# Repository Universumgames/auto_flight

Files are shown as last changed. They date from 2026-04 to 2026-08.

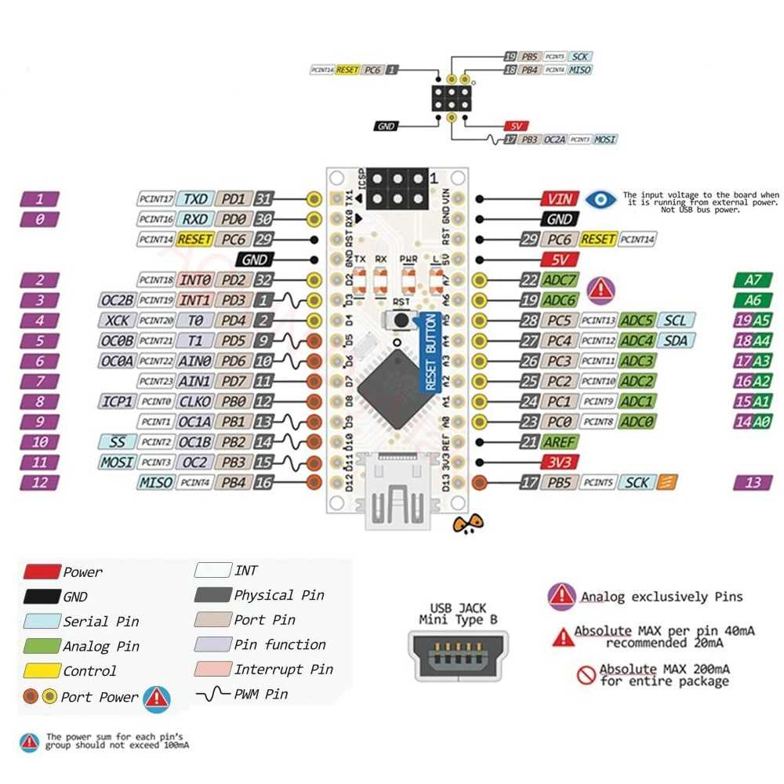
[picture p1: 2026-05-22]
resources/arduino-nano-pinout-pwm-lgr.jpg

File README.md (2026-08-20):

# Auto Flight

Autonomous glider for area-coverage flights — technical documentation.

"Auto Flight" is an autonomous glider that independently flies over predefined areas (e.g. agricultural fields) in a lawn-mower (meander) pattern. Navigation is achieved through a combination of GPS, accelerometer/gyroscope (IMU), magnetometer, and barometer. Throughout the flight, the plane stays in contact with a ground station via a long-range radio link (LoRa), which provides a web interface for mission planning and live monitoring. In an emergency, the plane can be taken over manually at any time via an off-the-shelf RC transmitter.

The system consists of three independent firmware/software projects (the flight controller in the plane, the ground station, and a servo/motor controller) as well as a number of shared components and tools:

| Project | Platform | Task |
|---|---|---|
| [`flight_controller/`](./flight_controller) | ESP-IDF (ESP32-S3) | Main computer in the plane: route planning, sensors, flight control, LoRa communication |
| [`base_station/`](./base_station) | ESP-IDF (ESP32-S3) | Ground station: WiFi access point, web UI server, LoRa relay |
| [`motor_controller/`](./motor_controller) | PlatformIO/Arduino (ATmega328) | Control-surface/motor actuation, SBUS reception, safety override |
| [`frontend_web/`](./frontend_web) | Vue 3 + TypeScript | Ground station user interface (mission planning, live telemetry) |
| [`shared_components/`](./shared_components) | ESP-IDF components | Shared building blocks for flight controller and ground station (LoRa, I2C, sensor drivers, data storage) |

The project is an individual student project in the "Mobile Robots" module and is currently at the stage of an advanced prototype. An ongoing development log with progress and issues encountered can be found in [`resources/learning.md`](./resources/learning.md).

# Objective and application scenario

## Basic idea

The starting point of the project (see [`Projekt_Idee.md`](./Projekt_Idee.md)) is an autonomous glider that flies over defined areas. The version implemented as part of this work covers the beginning of this scenario: communication with the ground station, configuration, and monitoring of the flight. The plane is already able to compute a route from the given area and make small corrections during the flight based on the accelerometer. However, flying the route is not yet fully autonomous, since altitude control and thrust control have not yet been flight-tested.

## Application scenario

The system is designed for use in mapping and agriculture. With the addition of a camera, the system could be used to inspect large areas (e.g. agricultural fields, solar parks, forests). The ground station allows planning of the area to be flown over, monitoring of the flight, and evaluation of the sensor data. The system is intended for use in rural areas with low building density and no no-fly zones.

## Bandwidth and data-storage concept

Since LoRa only offers very low bandwidth at long range, the radio link is deliberately limited to compact status and control data (position, sensor values, routes, connection status). Larger payloads such as camera images are, in the original idea, intended for local storage (SD card) or WiFi transfer after landing, and are deliberately not part of the LoRa link. This part is not implemented in the current feature set, since no camera payload has been integrated.

# Requirements and constraints

## Functional requirements

- Autonomous navigation along a strip pattern (waypoint sequence) computed from a user-defined polygon
- Determination of position, attitude (roll/pitch), heading, and altitude during flight from GPS, IMU, magnetometer, and barometer
- Remote configuration of the target area and monitoring of the flight via a web interface, reachable through a WiFi access point provided by the ground station
- Telemetry transmission (position, key sensor data, connection status, route) over a long-range radio link between plane and ground station
- Manual override of control surfaces and propulsion at any time via an RC transmitter, independent of the state of the flight controller

## Non-functional requirements and constraints

- **Range vs. bandwidth:** The radio link must work reliably even over larger distances (field size). This requires choosing LoRa (868 MHz, ISM band), with correspondingly low usable data rate, which necessitates a custom, frugal message protocol (see section "Technical implementation").
- **Real-time capability:** Flight control runs with a fixed cycle time of 50 ms in order to respond promptly to changes in attitude and heading.
- **Resource constraints:** As a glider, weight is a limiting factor for battery capacity, sensors, and servos. This limits both the available compute power (microcontroller instead of single-board computer) and the number of I2C sensors that can be operated simultaneously on a shared bus.
- **Fail-safety:** Manual override must not depend on the state of the flight controller, since the flight controller itself is the actual failure source it is meant to guard against.
- **Legal framework:** During the project, research into the legal framework for autonomous aircraft was carried out (see week 2 in [`resources/learning.md`](./resources/learning.md)), which in particular confirmed the need for manual control to be available at all times.

## Technical constraints

- Two identical Heltec WiFi LoRa 32 V3 boards (ESP32-S3 + integrated SX1262 LoRa module) as the central compute and radio units, one in the plane and one in the ground station
- An Arduino Nano (ATmega328) as a separate, simple servo/motor controller, connected via I2C to the flight controller and via SBUS to the RC receiver
- ESP-IDF (version 5.x) as the firmware base for the flight controller and ground station, with shared components in [`shared_components/`](./shared_components)
- Node.js/Vue 3 for the web interface, which is embedded as static files into the ground station's flash storage (no separate web server)

# System architecture

## Hardware architecture

### Main components

| Component | Location | Function |
|---|---|---|
| Heltec WiFi LoRa 32 V3 (ESP32-S3 + SX1262) | Plane, ground station (2×) | Main computer + LoRa radio module |
| Arduino Nano (ATmega328) | Plane | Servo/motor actuation, SBUS reception, safety override |
| GPS module (ATGM336H, NMEA) | Plane (ground station optional) | Position determination |
| MPU6050 (accelerometer + gyroscope) | Plane | Attitude determination (roll/pitch) |
| Magnetometer HMC5883L | Plane | Heading determination |
| Barometer (BME280) | Plane, ground station | Altitude determination via air pressure |
| Level shifter (3.3 V <-> 5 V) | Plane | I2C level adaptation between ESP32-S3 (3.3 V) and Arduino Nano (5 V) |
| Time-of-flight sensor TOF200C | Plane | Ground-distance measurement, intended for automatic landing |
| SBUS receiver | Plane | Reception of RC transmitter commands |
| 4× servo / ESC | Plane | Ailerons (differential), elevator, thrust, rudder |
| LittleFS storage | Ground station | Storage of the web UI files in flash |
| Batteries | Plane, ground station | Power supply |

The complete bill of materials can be found in [`BOM.md`](./BOM.md). The TOF200C distance sensor is part of the procurement list, but is not yet integrated into the firmware in the current feature set, since automatic landing, as described in the section "Known limitations and possible improvements", has not yet been implemented.

The magnetometer originally used was a QMC5883P, which was replaced with an HMC5883L during the project. Both associated datasheets are available under [`resources/`](./resources); the reason for the switch is explained in the section "Technical implementation and key design decisions".

### Schematics

The schematics for the plane and ground station were created with [Fritzing](https://fritzing.org/). The source files are available as [`assets/schematics_plane.fzz`](./assets/schematics_plane.fzz) and [`assets/schematics_base.fzz`](./assets/schematics_base.fzz), together with custom Fritzing parts created for modules without official Fritzing support ([BMP280 breakout](./assets/BMP280_Breakout_Board.fzpz), [GT-U8 GPS module](./assets/GT-U8-GPS-module.fzpz), [Heltec WiFi Kit 32 (V3)](./assets/Heltec WiFi Kit 32 (V3).fzpz)).

The wiring of the 4 servos is not shown in the schematic here, in order to keep it clear. The servos are connected directly to the Arduino Nano, which generates the PWM signals. PWM pins 9, 10, 11, and 12 were used for the left aileron, right aileron, elevator, and rudder. The mapping between servo and control surface is defined in the control logic in the ESP32 flight controller and can be adjusted as needed. In the Arduino code there is a fixed mapping: byte 0 -> servo 1, byte 1 -> servo 2, byte 2 -> servo 3, byte 3 -> servo 4. Which servo is assigned to which control surface is then defined in the flight control logic in the ESP32 flight controller.

**Plane:**

Plane schematic with Heltec LoRa32 V3, GPS, IMU, magnetometer, barometer and the link to the Arduino motor controller

Breadboard view of the wiring in the plane

**Ground station:**

Ground station schematic with Heltec LoRa32 V3, GPS and barometer

Breadboard view of the ground station wiring

### Mechanical design

Under [`3d_models/`](./3d_models) are the 3D-printed enclosure/mounting designs:

- **Ground station enclosure** ([`base_station_case.scad`](./3d_models/base_station_case.scad)): a two-piece enclosure (tray + lid) with a snap-fit connection, mounts for the main board (Heltec LoRa32 V3 + GPS module) and a daughterboard connected via cable (barometer), an SMA antenna feedthrough in the enclosure wall, and a pressure-equalization hole in the lid above the barometer.
- **Plane mounting plate** ([`plane_mount_plate.scad`](./3d_models/plane_mount_plate.scad)): according to a comment in the source code, a pure layout mockup showing the relative arrangement of the main board, two daughterboards, and the four control-surface servos. It is explicitly not a flight-worthy part (no fuselage mounting, no cable routing, no weight optimization).

### System topology

System topology: plane (flight controller, IMU, GPS, motor actuation, RC receiver) connected via LoRa to the ground station, which communicates with the web UI via WebSocket

The control surfaces can be actuated via the servos either by the flight controller (over I2C) or directly by the RC transmitter (over SBUS). Which path is active is decided exclusively by the Arduino in the plane (see "Manual override").

## Software architecture

### Project structure

| Path | Content |
|---|---|
| [`flight_controller/`](./flight_controller) | ESP-IDF firmware of the plane: route planning, sensors, flight control, LoRa communication |
| [`base_station/`](./base_station) | ESP-IDF firmware of the ground station: WiFi AP, web UI server, LoRa relay |
| [`motor_controller/`](./motor_controller) | Arduino firmware for servo/SBUS integration |
| [`frontend_web/`](./frontend_web) | Vue 3 web interface of the ground station |
| [`shared_components/`](./shared_components) | ESP-IDF components shared between flight controller and ground station (LoRa, I2C, sensor drivers, data storage) |
| [`python/`](./python) | Offline visualization of the computed flight routes |
| [`serial_plane_viz/`](./serial_plane_viz) | Tool for visualizing servo deflections over the serial interface |
| [`doc/`](./doc), [`resources/`](./resources) | Notes, pinouts, datasheets, bill of materials, development log |

`flight_controller` and `base_station` are two independent ESP-IDF projects, each with its own `sdkconfig`/`CMakeLists.txt`, both of which include the same components from `shared_components/` via `EXTRA_COMPONENT_DIRS`. This is the project's central reuse strategy: sensor drivers, I2C management, the LoRa radio stack, and the application protocol exist only once and are shared by both firmware projects, controlled via a project-wide compile flag (`FLIGHT_DEVICE_TYPE_PLANE` or `FLIGHT_DEVICE_TYPE_BASE_STATION`), which determines which role a device takes on in the protocol.
`motor_controller` is a standalone Arduino project that communicates with the flight controller over I2C and drives the control-surface servos and the motor. It is deliberately kept simple, since its only task is to move the servos and receive the SBUS signals from the transmitter.

### Communication layers

The connection between plane and ground station is split into three layers:

1. **Radio layer** ([`shared_components/lora_com`](./shared_components/lora_com)): controls the SX1262 radio module via the RadioLib library. Since a LoRa packet is limited to 255 bytes, this layer implements its own fragmentation of larger messages (header with message ID, fragment ID, and total fragment count), acknowledgement of each fragment via ACK with a timeout (2 s) and up to three retries, as well as periodic keep-alive pings (default: every 30 s) to monitor the connection in case no other message is sent.
2. **Application protocol** ([`shared_components/flight_com`](./shared_components/flight_com)): defines typed packets on top of the radio layer, including `SensorUpdate` (air pressure, heading), `PositionUpdate` (GPS position), `ComponentStatus` (connection status of the individual subsystems, override status, flight state), `PlannedRoutePacket`/`PlannedAreaPacket` (computed route / given area), and `FlightHistoryPacket` (flown path).
3. **Web link** (ground station -> browser): the ground station does not directly forward the received LoRa packets, but instead writes them into a central, thread-safe state store (`FlightStorage`, part of [`shared_components/flight_data`](./shared_components/flight_data)). An HTTP/WebSocket server reads from it and serializes the data separately as JSON for the web frontend. The LoRa format and the web JSON format are thus fully decoupled.

### Ground station web stack

The ground station opens a WiFi AP (default SSID, configurable via Kconfig, alternatively a "dev mode" in which it first tries to connect to an existing WiFi network instead) as well as an HTTP server. This serves:

- **Static files** of the web interface from a LittleFS flash partition (`/*` route as a fallback handler). The directory `base_station/static` is a symlink to `frontend_web/dist`, so that a frontend build is directly embedded as a flash image (`littlefs_create_partition_image` in [`base_station/CMakeLists.txt`](./base_station/CMakeLists.txt)).
- **REST API endpoints**: including `GET /api/status` (connection status), `POST`/`GET /api/area` (set/read target area), `GET /api/route` (query computed route). See "Ground station API reference" below for details.
- **WebSocket endpoint** (`GET /api/ws`): sends three message types to all connected clients every 5 seconds: `flight` (positions, planned/flown route), `connection` (connection status of all subsystems), `sensor` (air pressure, computed altitude, heading). Details below.

### Ground station API reference

All HTTP and WebSocket endpoints are registered in the ESP-IDF component [`base_station/components/frontend`](./base_station/components/frontend) (`FrontendHandlerClass::init()`), not in `base_controller`. At startup, `httpd_start` is called first, then the LittleFS partition is mounted, and finally the handlers are registered in a fixed order: `/api/ping`, `/api/ws`, the remaining REST endpoints, and finally the static file handler `/*`. This order is necessary because `/*`, as a wildcard, would otherwise shadow all more specific routes. In parallel, a FreeRTOS task starts that sends status packets via WebSocket every 5 seconds.

#### Data types

All endpoints exchange JSON, which is (de)serialized directly from the C++ structs in [`FrontendPackets.hpp`](./base_station/components/frontend/FrontendPackets.hpp) via `nlohmann::json`. The types in the frontend ([`frontend_web/src/types/`](./frontend_web/src/types)) mirror the same structures in TypeScript:

```ts
type Coordinate = { longitude: number; latitude: number }
type Route = Coordinate[]

type ConnectionState = "connecting" | "connected"
type FlightState = "planning" | "planned" | "flying" | "returning"

interface AreaDefinePacket {
  shape: Coordinate[]
}

interface PlannedRoutePacket {
  type: "plannedRoute"
  route: Coordinate[]
}

interface ConnectionUpdatePacket {
  type: "connection"
  baseConnectionState: ConnectionState
  lastContactBaseStationTimestamp: number
  planeConnectionState: ConnectionState
  lastContactPlaneTimestamp: number
  gpsConnectionBase: ConnectionState
  gpsConnectionPlane: ConnectionState
  barometerConnectionBase: ConnectionState
  barometerConnectionPlane: ConnectionState
  motorComConnectionPlane: ConnectionState
  magnetometerConnectionPlane: ConnectionState
  accelerometerConnectionPlane: ConnectionState
  manualOverridePlane: boolean
  flightState: FlightState
}

interface FlightUpdatePacket {
  type: "flight"
  basePosition: Coordinate
  basePositionUpdateTime: number
  planePosition: Coordinate
  planePositionUpdateTime: number
  flightRoute: Route
  flightRouteUpdateTime: number
  plannedRoute: Route
  plannedRouteUpdateTime: number
}

interface SensorUpdatePacket {
  type: "sensor"
  barometerPressureBase: number
  barometerPressurePlane: number
  calculatedAltitude: number
  headingPlane: number
}
```

`...Timestamp`/`...UpdateTime` fields are Unix timestamps, originating either from runtime or from the GPS signal. `ConnectionState`/`FlightState` are serialized as strings rather than numbers.

#### Endpoints

| Method | Path | Function | Type |
|---|---|---|---|
| GET | `/api/ping` | Liveness check | Text `"pong"` |
| GET | `/api/ws` | WebSocket upgrade, live telemetry | see below |
| GET | `/api/status` | Connection and flight state | `ConnectionUpdatePacket` |
| POST | `/api/area` | Set target area | Body: `AreaDefinePacket` |
| GET | `/api/area` | Query target area | `AreaDefinePacket` |
| GET | `/api/route` | Query computed route | `PlannedRoutePacket` |
| GET | `/*` | Static web UI files from LittleFS | — |

**WebSocket `/api/ws`**
After the upgrade, the client is registered and supplied with three messages every 5 seconds, distinguished by `type`: `FlightUpdatePacket`, `ConnectionUpdatePacket`, `SensorUpdatePacket` (type definitions above). If a client sends the text message `"ping"`, the server responds with `"pong"` (used in the frontend as a connection heartbeat). The type of the WebSocket message is currently distinguished via the first field `type` in the JSON object, not via WebSocket subprotocol mechanisms.

### Frontend

The web interface ([`frontend_web/`](./frontend_web)) is a Vue 3/TypeScript single-page application built with Vite. It guides the operator through mission preparation via a wizard:

- **Connection overview**: shows the live status of the base and plane connections as well as their subsystems (GPS, barometer, motor actuation, magnetometer), and only unlocks the next step once all connections are established.
- **Area planning**: drawing a target polygon on a Leaflet map (via `leaflet-draw`), transmitted to the ground station.
- **Route preview**: querying the route computed by the plane, displayed on the map together with the path flown so far.
- **Live telemetry**: continuous updates of position, route, and sensor values via the WebSocket connection, supplemented by a dedicated ping/pong heartbeat in the frontend to detect connection drops.

# Technical implementation and key design decisions

## Route planning

The [`route_planner`](./flight_controller/components/route_planner) generates a lawn-mower/boustrophedon pattern from a polygon drawn by the operator:

1. **Generate sweep lines**: equidistant, horizontal lines (parallel to latitude) are computed from the polygon's bounding box, spaced by the effective swath width.
2. **Clip to the polygon**: each line is intersected with the actual, possibly concave, polygon (geometry library [`homog2d`](https://github.com/skramm/homog2d)). Where multiple intersection points occur, only the outer segment is kept, so that holes and concave shapes are correctly excluded.
3. **Assemble the path**: the individual lines are alternately connected left-to-right and right-to-left into a continuous path. Additional intermediate points are inserted between two rows to produce a softer curved path instead of a sharp 180° turn.
4. **Interpolation**: finally, all segments longer than a configured maximum distance are subdivided into evenly spaced intermediate points, so that two consecutive waypoints are never further apart than this distance. This interpolation should later be usable for camera control and is not only relevant for flight control.

In the current implementation, the flight controller calls the route planner with a maximum point distance of 60 m, a swath width of 40 m, and an overlap factor of 20%, which corresponds to an effective row spacing of 32 m. These values are currently hardcoded in the source code and not configurable. For the later integration of a camera, this would be related to the camera's effective image width/FOV, the flight altitude, and a desired additional overlap between images, in order to determine the parameters for route planning.

## Flight control

The flight controller ([`FlightController`](./flight_controller/components/flight_controller)) runs as a FreeRTOS task with a fixed cycle of 50 ms and implements cascaded PI control for four control quantities:

- **Rudder (heading):** the target bearing is computed from the current GPS position and the next waypoint and compared with the measured compass heading. The normalized bearing error is mapped proportionally (P control) to the rudder.
- **Altitude hold:** the difference between target altitude (60 m) and measured altitude drives two parallel PI controllers: one for thrust and one for the target pitch angle, which in turn feeds into the pitch control as a setpoint (cascaded control).
- **Ailerons:** pure "wings-level" control (PI on roll angle), independent of any turn command. There is currently no coordinated turn; turning is done exclusively via the rudder.
- **Elevator:** PI control of the pitch angle towards the target pitch given by the altitude control.

Waypoint arrival is checked via the distance to the current position against a configurable radius (default 30 m). Once the last waypoint is reached, the internal flight state switches to "returning". In the current implementation, however, this has no effect yet. Unlike, for example, the telemetry interval or waypoint radius, controller gains and target altitude are hardcoded as constants in the source code rather than being Kconfig parameters.

## Sensors and data fusion

Sensor data processing is deliberately kept simple: there is **no** shared state estimator in use. Instead, each derived measurement is independently smoothed with a moving average and fed directly into the respective PI controller:

- **Attitude (roll/pitch):** computed exclusively from the direction of gravity from the accelerometer (`atan2` over the acceleration components), after a zero-point calibration at startup.
- **Heading:** computed directly from the raw magnetometer values (`atan2`), without tilt compensation relative to roll/pitch and without correction for magnetic declination. The value is then smoothed circularly (separate averaging of sine/cosine components, to correctly handle the jump at 0°/360°).
- **Altitude:** from barometric air pressure via the hydrostatic equation, relative to a ground reference pressure transmitted by the ground station. The computed altitude is thus relative to the starting point (AGL), not absolute (MSL).
- **Position:** directly from parsed GPS NMEA sentences, without additional filtering or dead reckoning. A position is only considered valid once a minimum number of satellites has been received.

This architecture should be understood as a pragmatic intermediate stage. It delivers usable, but more vibration- and noise-sensitive estimates than true sensor fusion (see "Known limitations").

## Communication between flight controller and motor controller

The Arduino motor controller is an I2C slave (address `0x42`) with a deliberately minimal, register-less protocol:

- **Write (flight controller → Arduino):** exactly 4 bytes, one signed value each in the range -100…100 for rudder, elevator, thrust, and differential aileron. Incomplete transfers are discarded. The last valid values are retained.
- **Read (Arduino → flight controller):** a single status byte indicating whether manual override is active. A successful read also serves as a connection check.

The Arduino independently monitors the freshness of incoming I2C messages and automatically reinitializes the I2C bus if no message has arrived for one second. This is a safeguard against stuck bus states, which were observed multiple times during the project.

## Manual override

The safety-critical decision of whether the plane is controlled autonomously or manually is deliberately not made in the flight controller, but on the Arduino. A fixed SBUS channel (channel 5) of the RC receiver is interpreted as an override switch. If its value exceeds the threshold of 1500 µs (neutral position), the Arduino drives the four servos directly from the SBUS channels and ignores the I2C values last received from the flight controller. The flight controller itself only reads the override status for display/telemetry purposes, but has no influence on it. This decoupling ensures that manual control is preserved even in the event of a crash or hang of the ESP32 firmware.
The current setup uses the MRFS01 SBUS receiver from Futaba (link to [Aliexpress](https://de.aliexpress.com/item/1005007253167246.html)). The SBUS receiver transmits the control commands to the Arduino over a serial interface (UART), but Futaba uses a special configuration of the UART interface. The Arduino library [SBUS](https://github.com/george-hawkins/arduino-sbus) supports this configuration, with a few hardware modifications for the Arduino Nano.
The Futaba SBUS receiver communicates over an inverted UART interface at 100000 baud, 8 data bits, 2 stop bits, and even parity. The Arduino Nano, however, does not have an inverted UART interface, so an inversion of the UART signals was implemented using a 2N2222 transistor. The circuit can be found in the schematic file `schematics_plane.fzz` or in the section [Schematics](#schematics).

## Key design decisions during the project

- **Switch from PlatformIO to ESP-IDF** for the flight controller and ground station (week 4 of the development log): triggered by difficulties in component management under PlatformIO. ESP-IDF also made it possible to build and test the same components natively on the host machine (see "Tests and evaluation").
- **Switch of the magnetometer from QMC5883P to HMC5883L**, along with switching the read mode from "continuous" to "single-read" (weeks 10 and 11): the originally installed QMC5883P responded unreliably and sometimes under changing I2C addresses. The deeper cause of a recurring bus failure was identified later: in continuous measurement mode, a read access during an ongoing internal measurement can put the sensor into a state that blocks the entire I2C bus or fills it with garbage data, instead of just returning a single faulty reading. Switching to individually requested measurements (single-read) fixes this behavior, since the sensor only allows read accesses after a measurement has completed.
- **Custom fragmentation protocol over LoRa**: since individual application messages (e.g. a complete planned route) can exceed the maximum LoRa packet size of 255 bytes, a custom fragmentation and acknowledgement scheme with message/fragment IDs, inspired by TCP, was developed.
- **Separation of radio protocol and web protocol**: the deliberate decoupling of the LoRa wire format and the WebSocket/REST JSON format via the central `FlightStorage` state store allows both sides to be developed further independently of each other.

## Supporting tools

Two tools support development but are not part of the actual flight software:

- [`python/`](./python): two small scripts for offline visualization of the sweep paths generated by the route planner, either as a simple 2D plot (`matplotlib`) or on an interactive map (`folium`).
- [`serial_plane_viz/`](./serial_plane_viz): a browser tool (three.js) that visualizes servo deflections (motor, roll, pitch, yaw), sent over a serial interface in the same value range as the motor controller's I2C protocol, on a simple 3D plane model. This is useful for debugging without a real plane.

# Tests and evaluation

## Automated tests

**Flight controller (native unit tests):** the `flight_controller` build system distinguishes between a real ESP-IDF firmware build and a native host build based on an environment variable. For the latter, a dedicated CMake compatibility layer exists that makes ESP-IDF components compilable as ordinary CMake libraries for the host, so that the business logic can be tested without real hardware (GoogleTest). In terms of content, the existing tests are limited exclusively to the **geometry of route planning**: correct detection of the outer polygon points, correct intersection computation between a line and the polygon, correct number/position of the generated sweep lines, and a monotonic course of the assembled sweep path. There are **no** automated tests for flight control (PI controllers), the sensor drivers, or the I2C protocol to the motor controller. This part is verified exclusively on real hardware.

**Frontend:** type checking (`vue-tsc`) and linting (ESLint/oxlint) run as basic quality assurance on every build. A Playwright E2E scaffold is set up. However, the only existing test is the unchanged scaffold test from the Vue project template; real tests covering actual functionality have not yet been implemented, due to the application's continuous changes and extensions.

## Evaluation based on the development history

The development log ([`resources/learning.md`](./resources/learning.md)) documents progress over twelve weeks and allows an honest assessment of the functionality actually achieved:

- Successfully implemented and put into operation: GPS evaluation, a working LoRa connection with acknowledgements and keep-alive pings, the I2C connection of barometer and IMU, and, after the hardware problems described above, a working magnetometer connection.
- Several fundamental technical problems had to be solved during development, including a necessary packet fragmentation for LoRa messages over 255 bytes, a deadlock in the event handler queue, and the I2C bus dropouts related to the magnetometer described above.
- Recurring I2C bus instability when operating multiple sensors on the same bus simultaneously was the longest-standing hardware/firmware problem during the project and, even with the implemented workarounds (bus recovery, single-read mode), should still be regarded as a fundamental residual risk.

# Known limitations and possible improvements

**Sensor fusion:** attitude determination is done purely from the accelerometer; a Kalman or complementary filter is not active, and the compass operates without tilt compensation or declination correction. As an improvement, the existing complementary filter and gyroscope integration should actually be incorporated into the control loop, and tilt compensation and declination should be added to the heading calculation.

**Control:** controller gains and target altitude are hardcoded instead of configurable, there is no coordinated turn (ailerons independent of the turn command), and the full control cascade has not been flight-tested. This could be improved by making the gains configurable via Kconfig or at runtime, carrying out systematic flight tests, and adding coordinated turn control.

**Mission parameters & configurability:** swath width, overlap factor, and maximum point distance are hardcoded in the source code for route planning (see the "Route planning" section) and not configurable, in order to tune them to different cameras (FOV, model), battery capacities, or plane sizes/weights; likewise, there is no configuration at all for coordinated operation of multiple planes (swarm configuration). It would make sense to make these mission parameters configurable via the web interface and to extend the communication/addressing layer (see "Radio link") so that multiple planes and base stations can be coordinated as a swarm.

**Path-planning algorithms:** currently only a sweep-line lawn-mower pattern is implemented; alternative coverage-path-planning algorithms have not been tried out or evaluated. A systematic evaluation of different algorithms in terms of flight distance, theoretical flight duration, and estimated battery capacity is still outstanding and would be a sensible next step to make route planning energy- and runtime-aware beyond pure geometry.

**Hardware robustness:** with multiple sensors connected, recurring I2C bus dropouts occur, which remain a residual risk despite workarounds. As an improvement, it would make sense to reconsider the bus topology (e.g. I2C multiplexer, separate buses) and carry out a hardware redesign of the wiring.

**Radio link:** no encryption is active, there is no device addressing (only point-to-point, relevant for multiple planes/base stations), and airtime is not controlled. There is potential for improvement in enabling encryption, adding addressing for multi-plane scenarios, and implementing control of maximum airtime.

**Test coverage:** only the route-planning geometry is automatically tested, the CI only builds the documentation and not the firmware or the frontend, and the frontend E2E test is unchanged scaffold code. Unit tests for control logic and protocol code should be added here, firmware/frontend build and tests should be added to the CI pipeline, and the Playwright test should be adapted to the real application.

**Frontend code:** the frontend is not yet finished. Still missing are further options for configuring the flight-route computation, flight monitoring once the flight has started, and a return-to-home function. There is also currently a problem loading the tiles for the OpenStreetMap map. Since the end device is on the base station's WiFi network, which does not offer internet access, the map view currently only works if a separate hotspot is opened or if one switches temporarily to mobile data to load the map. A SIM module would be a solution to this problem. Alternatively, switching to a native app communicating via Bluetooth would be an elegant option, as it would make it possible to use the phone's offline maps.

**Flight tests:** no real flight tests have been carried out, since altitude control and thrust control are not yet adequately implemented; in addition, the existing servo controls still need to be verified. As a next step, systematic flight tests should be carried out, possibly with a safety tether or in a cordoned-off test area.

**Camera integration:** the camera has so far been left out of this prototype. Image coverage is in principle computable from FOV and ground distance, but a reliable ground-distance measurement is still missing: the barometer and GPS only provide altitude above the starting point/sea level and fail in hilly or mountainous terrain without an accompanying elevation map; a LiDAR sensor for ranges beyond 40 m would also still need to be added. For image processing, there is the idea of fire/smoke detection. For this, one could try to run a small quantized CNN on an ESP (inspired by the project [ESP32 LLM](https://github.com/DaveBben/esp32-llm)). As a naive, more resource-efficient alternative, a simple heuristic algorithm could be used instead (e.g. gray/red proportion in the image, optionally supported by a thermal camera). Next steps would be connecting a real camera to this ESP32 prototype, integrating it into the overall process (flight controller/ground station), and a comparative test of both approaches (naive vs. CNN) in terms of detection quality and resource usage.

# Individual contributions

The project was carried out as an individual work (one author according to the task assignment and version control). Conception, the entire firmware development (flight controller, ground station, motor controller), development of the web interface, selection and integration of the hardware, and this documentation all come entirely from the same person. A division among multiple contributors therefore does not apply.
AI tools were used to a small extent to assist with refactoring or the development of the 3D visualization. However, the essential parts of the software development, in particular the system design, system structure, and system logic, were implemented without AI.

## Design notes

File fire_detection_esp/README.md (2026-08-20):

# fire_detection_esp

ESP-IDF firmware that runs the CNN trained in
[`fire_detection_training`](../fire_detection_training) on an ESP32, via
[TensorFlow Lite Micro](https://github.com/espressif/esp-tflite-micro)
(pulled in as a managed component -- see `main/idf_component.yml`).

Built and verified against ESP-IDF v5.4, target `esp32s3` (also builds
against plain `esp32`, just with less RAM headroom for the tensor arena --
see `main/inference.cpp`).

## Architecture

Two independent FreeRTOS tasks, started from `app_main()` in `main.cpp`:

- **`inference_task`** (`main.cpp`, pinned to core 1): grabs a frame from
  `image_provider.cpp`, runs it through `fire_inference_run()`
  (`inference.cpp`), logs the predicted class + confidence, repeats every 2s.
- **`i2c_task`** (`i2c_task.cpp`, pinned to core 0): a template for any other
  sensor work you want running concurrently -- owns the I2C bus via
  ESP-IDF's `driver/i2c_master.h`, polls a (placeholder) register, and
  exposes the latest reading through `i2c_task_get_latest()` behind a
  mutex. Point `SENSOR_I2C_ADDR`/`read_register()` at your actual sensor
  and adjust the protocol as needed.

These two tasks don't share any state, so there's no locking between them.
If you do need to pass data between tasks (e.g. feed a barometer reading
into a decision alongside the CNN output), either:

- a mutex-protected shared variable, like `i2c_task_get_latest()` already
  does, for "latest value" semantics, or
- a FreeRTOS queue (`xQueueCreate`/`xQueueSend`/`xQueueReceive`) if you need
  to hand off discrete events without dropping any.

This is the standard ESP-IDF concurrency model: FreeRTOS tasks, not OS
threads. If you'd rather write standard C++ (`std::thread`, `std::mutex`)
instead of the FreeRTOS primitives used here, ESP-IDF's `pthread` component
maps those onto FreeRTOS tasks for you underneath -- same mechanism, different
API surface. Either way, `xTaskCreatePinnedToCore`'s core argument (0 or 1)
and priority argument are how you control where and how eagerly a task runs;
see the comments in `main.cpp` and `i2c_task.cpp` for the reasoning behind the
current choices.

## Getting a model in

`main/model_data.hpp`/`.cpp` start out as a placeholder (an empty model,
`g_model_data_len == 0`) so the project builds out of the box. Before it
does anything useful:

1. Train a model: see [`../fire_detection_training/README.md`](../fire_detection_training/README.md).
2. Run `make export` there (or `python export_c_array.py`), which
   overwrites `main/model_data.hpp`/`.cpp` with your trained model as a
   C++ array, plus the class labels.
3. Rebuild this project.

`fire_inference_init()` (`main/inference.cpp`) checks for the placeholder
and logs a clear error instead of crashing if you forget step 1-2.

### If you change the model architecture

`inference.cpp` registers a fixed, minimal set of TFLM ops via
`MicroMutableOpResolver` (not `AllOpsResolver` -- that class doesn't exist
in the currently vendored esp-tflite-micro). If you change
`fire_detection_training/model.py`'s architecture, the op list can change
too, and you'll get an "Op not found" runtime error rather than a build
error. Re-check the actual op list with:

```python
import tensorflow as tf
interp = tf.lite.Interpreter(model_path="models/fire_smoke_cnn_int8.tflite")
interp.allocate_tensors()
print(sorted({d['op_name'] for d in interp._get_ops_details()}))
```

and update the `resolver.Add*()` calls (and the `MicroMutableOpResolver<N>`
count) in `inference.cpp` to match.

## Camera

No camera has been wired in (this was left as a deliberate open choice --
see `image_provider.cpp`). Right now `image_provider_get_frame()` fills the
buffer with a synthetic test pattern, which is enough to verify the whole
pipeline (build, flash, run inference, see varying output) without any
camera hardware.

To add a real camera: bring in the `espressif/esp32-camera` managed
component (add it to `main/idf_component.yml`), initialize it for your
specific board's pin mapping, and replace the body of
`image_provider_get_frame()` with `esp_camera_fb_get()` + a resize/convert
step down to the model's expected size (see the TODO comment in
`image_provider.cpp` for specifics). The model's expected input
width/height is available at runtime via `fire_inference_get_input_size()`.

## Build & flash

```bash
. $IDF_PATH/export.sh        # or: get_idf, depending on your shell setup
idf.py set-target esp32s3    # or esp32
idf.py build
idf.py -p PORT flash monitor
```

`sdkconfig.defaults` sets a custom, larger partition table
(`partitions.csv`) since TFLM's kernels + the embedded model push the app
image past ESP-IDF's default ~1MB factory partition. Requires 4MB+ flash.

## Known gaps / next steps

- No camera (see above) -- `image_provider.cpp` is a synthetic stand-in.
- `i2c_task.cpp` talks to a placeholder device address/register, not a real
  sensor.
- The tensor arena (`kTensorArenaSize` in `inference.cpp`) is sized for the
  default tiny model; if you grow the model or bump `IMAGE_SIZE` in
  `fire_detection_training/config.py`, watch for `AllocateTensors()`
  failures and grow the arena (or move it into PSRAM on an S3 board).
- No test coverage on the firmware side, matching the rest of this
  workspace's ESP-IDF projects (see the top-level README's "Known
  limitations" section) -- verification here has been build/flash/log-level
  only.

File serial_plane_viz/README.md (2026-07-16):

# Serial Plane Viz

A simple, standalone 3D visualization tool: reads four servo values (motor,
roll, yaw, pitch) from a serial port and animates a low-poly RC plane in the
browser accordingly. Built with plain HTML/JS + three.js, no build step.

## Layout

```
frontend/   Static web app (three.js scene, UI, data source clients)
bridge/     Optional Python serial-to-WebSocket bridge (fallback for
            browsers without Web Serial support)
```

## Wire format

One line per update, comma-separated raw values in the range -100..100
(0 = neutral/center) — the same range `motor_controller` receives over I2C
(as `int8_t`) before its `mapToServo()` converts to actual PWM microseconds:

```
0,62,0,-38\n
```

By default the four fields are read as `yaw, pitch, motor, roll`, in that
order.

## Configuring channel order

The wire order is remapped in exactly one place, `frontend/js/config.js`:

```js
// Reorder this array to match your transmitter/receiver's actual wire order.
// Nothing else in parser.js / plane.js needs to change.
export const CHANNEL_ORDER = ['yaw', 'pitch', 'motor', 'roll'];
```

Edit the array order (and `CHANNEL_TYPE` if a channel's normalization should
change) and reload the page — parsing and rendering adapt automatically.

## Baud rate

The default baud rate (115200) lives in one place per side: `DEFAULT_BAUD_RATE`
in `frontend/js/config.js` (used by Web Serial, editable in the UI too) and
`DEFAULT_BAUD_RATE` in `bridge/config.py` (used by the Python bridge, override
with `--baud`).

The bridge script serves the `frontend/` static files itself (on
`http://localhost:8000` by default), so it's the only thing you need to run
for any bridge-based setup below. Pass `--no-http` if you'd rather serve the
frontend yourself (e.g. `python3 -m http.server`, needed for a Web-Serial-only
setup with no bridge at all).

## Quick start — no hardware (mock demo)

```sh
cd bridge
python3 -m venv .venv
source .venv/bin/activate
pip install -r requirements.txt
python3 serial_to_ws_bridge.py --mock
```

Open `http://localhost:8000`, click **Connect via WS Bridge**, and you
should see the propeller spin and the plane bank, pitch, and yaw smoothly.

## Quick start — real hardware, Web Serial (Chrome/Edge only)

Web Serial requires a secure context; `localhost` qualifies. No Python
bridge needed — just serve the frontend:

```sh
cd frontend
python3 -m http.server 8000
```

Open `http://localhost:8000` in Chrome or Edge, click **Connect via Web
Serial**, and select your device's serial port.

## Quick start — real hardware, Python bridge (any browser)

```sh
cd bridge
python3 -m venv .venv
source .venv/bin/activate
pip install -r requirements.txt
python3 serial_to_ws_bridge.py
```

If `--port` isn't given, the bridge lists detected serial ports and prompts
you to pick one (by number or by typing a custom device path):

```
Available serial ports:
  [0] /dev/tty.usbserial-1420  (USB Serial)
  [1] /dev/tty.Bluetooth-Incoming-Port  (n/a)
Select a port [0-1] or enter a custom path: 0
```

Pass `--port /dev/tty.usbserial-XXXX` directly to skip the prompt.

If the serial connection drops (device unplugged, power cycle, etc.), the
bridge automatically retries the same port every `RECONNECT_DELAY_SECONDS`
(default 2s, in `bridge/config.py`) until it reconnects — no need to restart
the script.

Open `http://localhost:8000`, then click **Connect via WS Bridge**. Use this
path for Firefox/Safari, or any setup where Web Serial isn't available.

## Camera controls

Drag to orbit, scroll to zoom (three.js `OrbitControls`).

## Debug view

Click **Show Debug** to show the latest incoming line, as both raw text and
its parsed channel values (updates in place, no scrollback). A
malformed/dropped line is shown in red with no parsed values — useful for
spotting wiring or baud-rate issues.

## Limitations

The plane body itself is static — only the propeller and the control
surfaces (ailerons, elevator, rudder) move, deflecting in proportion to
their channel value. There's no integrated flight dynamics or whole-plane
attitude change. All angle/speed constants live in one `LIMITS` block at the
top of `frontend/js/plane.js` for easy tuning.

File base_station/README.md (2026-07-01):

# Base Station

ESP-IDF firmware for the ground station of the [Auto Flight](../README.md) project — an autonomous glider that flies pre-planned coverage patterns over an area. The base station hosts a WiFi access point and a web UI for planning missions and monitoring the plane, and talks to the plane over a long-range LoRa link.

Runs on a Heltec WiFi LoRa 32 V3 (ESP32-S3 + SX1262 LoRa), the same board as the [flight_controller](../flight_controller).

## What it does

- **WiFi access point + web UI**: brings up a WiFi AP (or joins an existing network in dev mode) and serves the built [frontend_web](../frontend_web) app from a LittleFS partition ([wifi_helper](components/wifi_helper), [frontend](components/frontend)).
- **REST + WebSocket API**: exposes endpoints to define/read the planned coverage area and route, read connection status, and a WebSocket that pushes live flight/connection/sensor updates every 5 seconds ([frontend](components/frontend)).
- **LoRa telemetry link**: receives the plane's position, sensor and route packets and component-status updates over LoRa, and sends the planned coverage area back to the plane ([base_controller](components/base_controller), using the shared [lora_com](../shared_components/lora_com)/[flight_com](../shared_components/flight_com) components).
- **Local sensors**: reads its own barometer and GPS so the base's altitude/pressure/time reference is available alongside the plane's ([base_controller](components/base_controller)).

See the component READMEs for details: [base_controller](components/base_controller/README.md), [frontend](components/frontend/README.md), [wifi_helper](components/wifi_helper/README.md).

## Prerequisites

- [ESP-IDF](https://docs.espressif.com/projects/esp-idf/en/latest/esp32s3/get-started/index.html) v5.x. A devcontainer is provided (`.devcontainer/`) if you prefer not to install it locally.
- [Node.js](https://nodejs.org/) 20.19+/22.12+ and npm, to build the [frontend_web](../frontend_web) app served by this firmware.

## Building & running

Build and flash the web UI's static files into the `storage` LittleFS partition first, since the firmware serves them:

```sh
cd ../frontend_web
npm install
npm run build        # outputs to frontend_web/dist, picked up as the `static` partition image
```

Then build and flash the firmware:

```sh
cd base_station
idf.py set-target esp32s3
idf.py menuconfig   # optional, see Configuration below
idf.py build
idf.py -p <PORT> flash monitor
```

`idf.py build` (via `littlefs_create_partition_image` in [CMakeLists.txt](CMakeLists.txt)) packages the `static` directory into the `storage` partition and flashes it alongside the app image, so the frontend build above must happen before flashing.

For frontend-only development against a running base station (no reflashing needed for UI changes), run `npm run dev` in `frontend_web` instead and point it at the base station's IP.

## Configuration

Most runtime configuration is exposed through `idf.py menuconfig`, backed by each component's `Kconfig`:

- **WiFi** ([components/wifi_helper/Kconfig](components/wifi_helper/Kconfig)): AP SSID/password (`WIFI_AP_SSID`/`WIFI_AP_PASSWORD`), hostname (`WIFI_DEVICE_HOSTNAME`), and `WIFI_DEV_MODE` to join an existing network instead of hosting an AP. For local dev, credentials can also go in an untracked `components/wifi_helper/secrets.h` (see [wifi_helper README](components/wifi_helper/README.md)) instead of Kconfig.
- **LoRa link** ([shared_components/lora_com/Kconfig](../shared_components/lora_com/Kconfig)): frequency, TX power, spreading factor, bandwidth, coding rate, sync word, ping interval, SPI/DIO pins. Must match the `flight_controller`'s settings for the two to talk to each other.
- **GPS** ([shared_components/gps/Kconfig](../shared_components/gps/Kconfig)): RX/TX pins and UART number.
- **I2C bus** ([shared_components/i2c_manager/Kconfig](../shared_components/i2c_manager/Kconfig)): SDA/SCL pins shared by the local barometer/GPS.

Flight area and mission parameters are configured at runtime from the web UI rather than via Kconfig.

## Repository layout

| Path | What it is |
|---|---|
| [components/base_controller](components/base_controller) | Top-level orchestrator: wires up sensors, LoRa comms and the frontend, and ties plane telemetry to local data. |
| [components/frontend](components/frontend) | HTTP/WebSocket server hosting the web UI and its REST/WebSocket API. |
| [components/wifi_helper](components/wifi_helper) | WiFi AP/station setup. |
| [static/](static) | Built `frontend_web` output, packaged into the `storage` LittleFS partition. |
| [shared_components (../shared_components)](../shared_components) | ESP-IDF components shared with `flight_controller`: LoRa comms, I2C manager, GPS, barometer, magnetometer, flight data storage. |

## Development notes

- `base_station` is an independent ESP-IDF project (its own `sdkconfig`/`CMakeLists.txt`) that pulls in [`../shared_components`](../shared_components) via `EXTRA_COMPONENT_DIRS` in [CMakeLists.txt](CMakeLists.txt).
- `FLIGHT_DEVICE_TYPE_BASE_STATION` is defined project-wide (see [CMakeLists.txt](CMakeLists.txt)) to select base-station-specific behavior in shared components.
- The plane/base-station wire protocol lives in [shared_components/lora_com](../shared_components/lora_com) and [shared_components/flight_com](../shared_components/flight_com); the equivalent TypeScript types for the web UI are under [frontend_web/src/stores](../frontend_web/src/stores).

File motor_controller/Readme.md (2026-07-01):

# Motor Controller

An Arduino Nano that sits between the RC receiver and the four control
servos/ESC of the plane. It normally takes its servo targets over I2C from
the flight controller (ESP32), but falls back to reading the SBUS RC
receiver directly if the pilot flips a manual-override switch, so the plane
stays flyable even if the flight controller crashes or loses power.

## Pinout

| Signal | Pin |
|---|-----|
| SBUS Receiver | Rx  |
| I2C SDA | A4  |
| I2C SCL | A5  |
| Servo 1 | D9  |
| Servo 2 | D10 |
| Servo 3 | D11 |
| Servo 4 | D12 |

Servo 1–4 map to aileron differential, pitch, thrust and rudder respectively
(the same order the flight controller sends them in, see
[I2C protocol](#i2c-protocol)).

## Inner working / mapping

- All RC channels and the I2C payload use a normalized `[-100, 100]` range,
  where `0` is center/neutral.
- `mapToServo()` linearly maps that range to the standard `[1000, 2000] µs`
  RC PWM pulse width (`1500 µs` = center), clamping out-of-range input first.
- **Manual override**: SBUS channel 5 is read every loop; if its normalized
  value is `> 50`, the board drives the servos directly from SBUS channels
  1–4 instead of the last values received over I2C. This is the safety
  fallback — flipping the corresponding switch on the transmitter takes the
  flight controller out of the loop entirely.
  - Note: the checked-in build currently defines `DEBUG_PLANE`/`DEBUG_I2C`,
    which forces `manualOverride` to `false` in `loop()` regardless of the
    switch, and also skips `sbus.begin()` in favor of a `Serial` debug
    console. Remove those defines for a normal flight build.
- `loop()` just re-evaluates and re-writes all four servos every iteration —
  there is no fixed frame rate; a servo simply holds its last commanded
  position until the next write.

## I2C protocol

The Arduino is an **I2C slave** at address **`0x42`** (`Wire.begin(0x42)`,
100 kHz bus clock as configured on this side — actual clock is dictated by
the master). There is no register addressing; it is a plain fixed-size
write / single-byte read protocol.

### Write (master → Arduino): set servo targets

Master must write **exactly 4 bytes**, each a signed `int8_t` in
`[-100, 100]`:

| Byte | Meaning |
|---|---|
| 0 | Servo 1 (aileron diff) target  |
| 1 | Servo 2 (pitch) target |
| 2 | Servo 3 (thrust) target |
| 3 | Servo 4 (rudder) target |

Effect: replaces all four stored target values at once (there is no partial
update — every write must supply all 4 bytes). These values are applied to
the servos on the next `loop()` iteration, but only while manual override is
*not* active; if the RC override switch is engaged, I2C writes are still
accepted and stored but have no visible effect until override is released.

If fewer than 4 bytes are received, the whole packet is discarded and the
previously stored values are kept unchanged.

### Read (master ← Arduino): status / liveness

A master read returns a single byte: `1` if manual override is currently
active (the board is ignoring I2C targets and flying off the RC receiver),
`0` otherwise. Since any successful read implies the slave acked its
address, this same read also doubles as a "is the controller connected and
responding" check regardless of the byte's value.

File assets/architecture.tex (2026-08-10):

%% System architecture diagram — shared between the presentation slides
%% (presentation/slides/02_architecture.tex) and the README.
%%
%% Render to SVG with:  make -C .. render_architecture   (see root Makefile)
\documentclass[tikz, border=6pt]{standalone}

\usepackage{fontspec}
\usepackage{tikz}
\usetikzlibrary{arrows.meta, positioning, shapes.geometric, backgrounds, shadows, fit}

%% ---- Fonts (matches presentation/preamble.sty: metropolis defaults to sans) ----
\setsansfont{FiraSans}[
  Extension      = .otf,
  UprightFont    = *-Regular,
  BoldFont       = *-Medium,
  ItalicFont     = *-Italic,
  BoldItalicFont = *-MediumItalic ]
\setmonofont{FiraMono}[
  Extension   = .otf,
  UprightFont = *-Regular,
  BoldFont    = *-Bold ]
\renewcommand{\familydefault}{\sfdefault}

%% ---- Colour palette (aviation-inspired, matches presentation/preamble.sty) ----
\definecolor{skyblue}{HTML}{2A6FDB}
\definecolor{deepnavy}{HTML}{16324F}
\definecolor{signal}{HTML}{E4572E}
\definecolor{leaf}{HTML}{2F9E44}
\definecolor{cloud}{HTML}{F4F6F8}
\definecolor{slate}{HTML}{55606B}

%% ---- Reusable node/edge styles (copy of presentation/preamble.sty) ----
\tikzset{
  box/.style={draw=deepnavy, thick, rounded corners=4pt, fill=cloud,
              align=center, minimum height=1.05cm, minimum width=2.6cm,
              font=\small, text=deepnavy, drop shadow={shadow xshift=1pt, shadow yshift=-1pt, opacity=0.2}},
  link/.style={-{Stealth[length=3mm]}, thick, skyblue},
  biln/.style={{Stealth[length=3mm]}-{Stealth[length=3mm]}, thick, signal},
}

\begin{document}
\begin{tikzpicture}[node distance=1.1cm and 1.6cm]
  % ---- Plane side ----
  \node[box, fill=skyblue!8] (fc) {\textbf{Flight controller}\\[-2pt]{\scriptsize ESP32-S3 · ESP-IDF}};
  \node[box, above left=0.55cm and -0.5cm of fc, minimum height=0.8cm] (imu)
    {\scriptsize IMU · Magnetometer · Barometer};
  \node[box, above right=0.55cm and -0.5cm of fc, minimum height=0.8cm] (gps)
    {\scriptsize GPS};
  \node[box, below=0.55cm of fc, minimum height=0.8cm] (mc)
    {\scriptsize Motor ctrl (Arduino)\\[-2pt]4 servos};
  \node[box, below=0.55cm of mc, minimum height=0.8cm] (rc)
    {\scriptsize RC receiver};

  % ---- Base side ----
  \node[box, right=2.5cm of fc, fill=leaf!8] (bs)
    {\textbf{Base station}\\[-2pt]{\scriptsize ESP32-S3 · WiFi AP}};
  \node[box, above=0.55cm of bs, minimum height=0.8cm] (bssens)
    {\scriptsize Barometer · GPS};
  \node[box, right=1.5cm of bs, fill=signal!8, minimum width=2.2cm] (web)
    {\textbf{Web UI}\\[-2pt]{\scriptsize Vue 3 · Leaflet}};

  % ---- Edges ----
  \draw[link] (imu) -- node[left, font=\scriptsize, text=slate]{I\textsuperscript{2}C} (fc);
  \draw[link] (gps) -- node[right, font=\scriptsize, text=slate]{Serial} (fc);
  \draw[link] (bssens) -- (bs) node[midway, right, font=\scriptsize, text=slate] {I\textsuperscript{2}C};;
  \draw[biln]  (fc) -- (mc) node[midway, right, font=\scriptsize, text=slate] {I\textsuperscript{2}C};
  \draw[link]  (rc) -- (mc) node[midway, right, font=\scriptsize, text=slate] {SBUS};
  \draw[biln]  (fc) -- node[above, font=\scriptsize\bfseries, text=signal]{LoRa}
                      node[below, font=\scriptsize, text=slate]{SX1262} (bs);
  \draw[biln]  (bs) -- node[above, font=\scriptsize, text=slate]{WebSocket} (web);

  % background groupings
  \begin{scope}[on background layer]
    \node[fit=(imu)(gps)(fc)(mc)(rc), draw=skyblue!40, dashed, rounded corners,
          inner sep=8pt, label={[skyblue, font=\scriptsize\bfseries]above:PLANE}] {};
    \node[fit=(bs)(bssens)(web), draw=leaf!40, dashed, rounded corners,
          inner sep=8pt, label={[leaf!70!black, font=\scriptsize\bfseries]above:GROUND}] {};
  \end{scope}
\end{tikzpicture}
\end{document}

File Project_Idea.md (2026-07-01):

# Initial Idea

## Basic Idea
An autonomous glider that flies over predefined areas, such as fields, and photographs them. The images can then be used, for example, to estimate crop yields, detect weeds, or identify other areas requiring action. In an emergency, the aircraft should be able to be controlled manually via a remote control.

## Communication, Configuration and Navigation
The aircraft communicates via LoRa with a base station, which provides a website via a hotspot that allows configuration of the flight area and other data.

An accelerometer, barometer, and magnetometer are used to determine the altitude and attitude of the aircraft. GPS is used to determine the correct position and thus ensure the automatic flying of the calculated waypoints.

## Possible Uses
By extending the system with a camera, aerial images can be captured and then used for the analysis of agricultural land.

Communication via LoRa allows for a long range but low bandwidth. It is therefore necessary to minimize the amount of data transmitted over LoRa. The images can therefore be stored on an SD card, with only the relevant data, such as GPS coordinates and status information, being transmitted via LoRa. As an alternative to storage on an SD card, which would have to be read out manually, the aircraft could transmit the images to the base station via WiFi upon landing. This would allow for faster and easier evaluation of the images, since they would be directly available on the base station's computer.

## Takeoff and Landing
For takeoff, the aircraft should be launched by hand and immediately begin automatic navigation. For landing, the aircraft should return to the starting point and either be landed manually, caught, or attempt to land gently on a meadow using a precise laser rangefinder.

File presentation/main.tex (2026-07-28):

%% Auto Flight — project presentation
%% Build with:  make        (uses latexmk + xelatex)
%% Theme: metropolis (modern beamer theme, Fira fonts)

\documentclass[aspectratio=169,11pt]{beamer}

\usetheme{metropolis}
\usepackage{preamble}

%% ---- Title metadata ----
\title{Auto Flight}
\subtitle{An autonomous survey glider with a LoRa ground station}
\author{Tom Arlt}
\institute{Mobile Robotics}
\date{\today}

\begin{document}

\maketitle

% Individual slides live in slides/*.tex
\input{slides/01_idea}
\input{slides/02_architecture}
\input{slides/03_flight}
\input{slides/04_communication}
\input{slides/05_lessons_learned}
\input{slides/06_status}

\begin{frame}[standout]
  Und jetzt eine kleine Demo
\end{frame}

%% ---- Closing ----
\begin{frame}[standout]
  Thank you.\\[0.4em]
  \small\normalfont Questions welcome.
\end{frame}

\end{document}

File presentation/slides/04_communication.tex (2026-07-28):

\begin{frame}{Communication \& ground control}
  \begin{columns}[T,onlytextwidth]
    \begin{column}{0.5\textwidth}
      \textbf{\faBroadcastTower\; Long-range telemetry}
      \begin{itemize}
        \item Plane $\leftrightarrow$ base over \hilite{LoRa} (RadioLib / SX1262)
        \item Eigenes Protokoll Layer (Transport und Application Layer)
        \item Überträgt Position, Sensoren, Routen \& Komponenten-Status
              Updates, ACKs and keep-alive pings
        \item \emph{Long range, low bandwidth} — nur essenzielle Daten
      \end{itemize}
    \end{column}
    \begin{column}{0.5\textwidth}
      \textbf{\faGlobe\; Web ground control}
      \begin{itemize}
        \item Base station öffnet einen \hilite{WiFi access point}
        \item Stellt ein Webinterface zur Verfügung \hilite{Vue 3 + TypeScript + Leaflet}
        \item Abzudeckender Bereich frei wählbar, Route kann direkt im Browser gezeichnet werden
        \item Live map, telemetry \& connection status über
              \hilite{WebSocket}
      \end{itemize}

      \vspace{0.4em}
      \chip{signal}{position} \chip{skyblue}{sensors}
      \chip{leaf}{route} \chip{slate}{status}
    \end{column}
  \end{columns}
\end{frame}

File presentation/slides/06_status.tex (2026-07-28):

\begin{frame}{Status \& outlook}
  \begin{columns}[T,onlytextwidth]
    \begin{column}{0.5\textwidth}
      \textbf{\faCheckCircle\; Working today}
      \begin{itemize}
        \item Setup und Routenplanung
        \item LoRa link und Monitoring
        \item Web UI: Konfiguration Überwachung
        \item I\textsuperscript{2}C sensor stack
        \item SBUS manual override
      \end{itemize}
    \end{column}
    \begin{column}{0.5\textwidth}
      \textbf{\faRoad\; Next steps}
      \begin{itemize}
        \item Robusteres Interface und Application Layer Kommunikation
        \item I\textsuperscript{2}C Kommunikation robuster
        \item automatische Motor und Höhenkontrolle
        \item Testen und Fine-Tuning
        \item Kamera Einbindung, Aufnahmen und Übertragung
        \item SIM Integration in der Base Station für Internetzugriff wenn im Konfigurationsnetzwerk
      \end{itemize}
    \end{column}
  \end{columns}
\end{frame}

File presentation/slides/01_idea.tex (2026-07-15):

\begin{frame}{The idea}
  \begin{columns}[T,onlytextwidth]
    \begin{column}{0.58\textwidth}
      \hilite{Autonomes Flugzeug} zum großflächigem Monitoring

      \bigskip
      \begin{itemize}
        \item mithilfe von GPS, Barometer und IMU \alert{selbstständig} über ein vorgegebenes Gebiet fliegen
        \item Kommunikation und Konfiguration über eine \alert{LoRa}-basierte Basis Station
        \item switch zu manueller Steuerung per RC-Fernsteuerung möglich
      \end{itemize}
    \end{column}
    \begin{column}{0.38\textwidth}
      \centering
      \begin{tikzpicture}[scale=0.95]
        % ground
        \fill[leaf!15] (-1.9,-1.4) rectangle (1.9,-1.0);
        \draw[leaf!50, thick] (-1.9,-1.0) -- (1.9,-1.0);
        % lawn-mower sweep pattern
        \draw[skyblue, thick, rounded corners=2pt]
          (-1.5,-0.8) -- (1.5,-0.8) -- (1.5,-0.45) -- (-1.5,-0.45)
          -- (-1.5,-0.10) -- (1.5,-0.10) -- (1.5,0.25) -- (-1.5,0.25);
        % plane glyph
        \node[signal, font=\Huge] at (0.6,1.05) {\faPlane};
        \node[font=\scriptsize\bfseries, text=slate] at (0,-1.62)
          {Boustrophedon coverage path};
      \end{tikzpicture}

      \medskip
      \chip{leaf}{survey}\; \chip{skyblue}{autonomous}\; \chip{signal}{LoRa}
    \end{column}
  \end{columns}
\end{frame}

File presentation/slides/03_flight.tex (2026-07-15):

\begin{frame}{Autonomous flight}
  \begin{columns}[T,onlytextwidth]
    \begin{column}{0.5\textwidth}
      \metroset{block=fill}
      \begin{block}{\faDrawPolygon\; Routen Planung}
        Im Web Interface kann beliebig ein Gebiet markiert werden, dass der Flieger autonom abfliegen soll
      \end{block}
      \begin{block}{\faSlidersH\; PID steering}
        Aileron, pitch und thrust sind gesteuert durch \hilite{PID loops} um von Waypoint zu Waypoint zu fliegen
      \end{block}
    \end{column}
    \begin{column}{0.5\textwidth}
      \centering
      \begin{tikzpicture}[scale=1.0, font=\scriptsize]
        % surveyed area, marked in the web interface
        \fill[skyblue!12] (0,0) rectangle (3.4,2.4);
        \draw[slate, dashed] (0,0) rectangle (3.4,2.4);

        % boustrophedon (lawnmower) waypoints: top-left to bottom-right
        \foreach \n/\x/\y in {1/0/2.4, 2/3.4/2.4, 3/3.4/1.2, 4/0/1.2, 5/0/0, 6/3.4/0}{
          \node[circle, fill=skyblue, text=white, inner sep=1.6pt] (w\n) at (\x,\y) {\n};
        }
        \draw[signal, thick, -{Stealth[length=2mm]}] (w1)--(w2);
        \draw[signal, thick, -{Stealth[length=2mm]}] (w2)--(w3);
        \draw[signal, thick, -{Stealth[length=2mm]}] (w3)--(w4);
        \draw[signal, thick, -{Stealth[length=2mm]}] (w4)--(w5);
        \draw[signal, thick, -{Stealth[length=2mm]}] (w5)--(w6);
        \node[slate] at (1.7,-0.4) {waypoints from route planner};

        % control-surface legend
        \node[deepnavy, anchor=west] at (-0.4,2.9) {\faPlane\; controls:};
        \node[anchor=west, text=slate] at (1.3,2.9) {aileron · pitch · thrust};
      \end{tikzpicture}

      \vspace{0.6em}
      \begin{alertblock}{\faHandPaper\; Manual override}
        Durch einen SBUS RC Empfänger kann jederzeit die manuelle Kontrolle übernommen werden
      \end{alertblock}
    \end{column}
  \end{columns}
\end{frame}

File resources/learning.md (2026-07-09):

- [Weekly Learning Log](#weekly-learning-log)
  - [Week 1 (2026-04-24 - 2026-04-30)](#week-1-2026-04-24---2026-04-30)
  - [Week 2 (2026-05-01 - 2026-05-07)](#week-2-2026-05-01---2026-05-07)
  - [Week 3 (2026-05-08 - 2026-05-14)](#week-3-2026-05-08---2026-05-14)
  - [Week 4 (2026-05-15 - 2026-05-21)](#week-4-2026-05-15---2026-05-21)
  - [Week 5 (2026-05-22 - 2026-05-28)](#week-5-2026-05-22---2026-05-28)
  - [Week 6 (2026-05-29 - 2026-06-04)](#week-6-2026-05-29---2026-06-04)
  - [Week 7 (2026-06-05 - 2026-06-11)](#week-7-2026-06-05---2026-06-11)
  - [Week 8 (2026-06-12 - 2026-06-18)](#week-8-2026-06-12---2026-06-18)
  - [Week 9 (2026-06-19 - 2026-06-25)](#week-9-2026-06-19---2026-06-25)
  - [Week 10 (2026-06-26 - 2026-07-02)](#week-10-2026-06-26---2026-07-02)
  - [Week 11 (2026-07-03 - 2026-07-09)](#week-11-2026-07-03---2026-07-09)
  - [Week 12 (2026-07-10 - 2026-07-16)](#week-12-2026-07-10---2026-07-16)
- [Plans to do next](#plans-to-do-next)
- [Outlook](#outlook)

# Weekly Learning Log

## Week 1 (2026-04-24 - 2026-04-30)
- Project planning
- what components do I need

## Week 2 (2026-05-01 - 2026-05-07)
- researching legal issues with automatic drone
- project setup
- getting gps to work and decoding gps data

## Week 3 (2026-05-08 - 2026-05-14)
- researching and implementing simple path planning algorithm
- learning how to unit test and setting up unit tests for path planning
- re-learning how to fly and airplane

## Week 4 (2026-05-15 - 2026-05-21)
- switching to and learning to compile with the ESP-IDF and getting everything to compile (partly to fix issues with Platformio, using shared components and more easily run and debug unit tests on host machine)
- learning about component management and how to set up a project with shared components
- issues:
  - getting ESP-IDF to work with components
  - understanding components and dependency management

## Week 5 (2026-05-22 - 2026-05-28)
- setting up webserver for configuration and control
- getting WiFi working on base station
- learning about getting started with LoRa
- start with simple network stack over LoRa
- issues:
  - getting LoRa to work
  - understanding how to implement a network stack over LoRa

## Week 6 (2026-05-29 - 2026-06-04)
- getting LoRa connection working with acknowledgements and pings
- getting I2C working for barometer and gyroscope
- issues:
  - getting I2C working with multiple devices and libraries

## Week 7 (2026-06-05 - 2026-06-11)
- integrating components
- debugging and fixing LoRa communication and serialization issues
- issues:
  - fixing serialization, specifically arrays/vectors

## Week 8 (2026-06-12 - 2026-06-18)
- fixing serialization issues
- further integrating components and testing, fixing bugs
- issues:
  - trying to fix lora message fragmentation for packages larger than 255 bytes -> writing custom packet splitter
  - event handler queue deadlock

## Week 9 (2026-06-19 - 2026-06-25)
- writing orientation helpers for auto pilot
- get accellerometer working
- issues:
  - accelerometer not outputting correctly
  - calculate yaw and yaw drift
  
## Week 10 (2026-06-26 - 2026-07-02)
- soldering pcbs
- getting magnetometer working
- issues:
  - getting correct library working
  - non functional magnetometer
  - I2C stopped working on flight controller completely
  - Magnetometer answering to different addresses each time
- resolution ideas
  - getting HMC5883L magnetometer instead

## Week 11 (2026-07-03 - 2026-07-09)
- issues: 
  - I2C bus not working with constant disconnects
  - Magnetometer get stuck sending static (and wrong) data once the bus has one misread
- resolutions
  - switch Magnetometer read mode from continuous to single read mode
    interesting fact: when using continuous mode the magnetometer measures the magnetic field at a given frequency and stores the data in the output registers. When reading these registers via the I2C bus, instead of sending garbage (reading while the magnetometer is writing) or waiting or the last measurement, the magnetometer will lock up and destroys the I2C with garbage data. The solution, switching to single read mode, will wait for the magnetometer to finish measuring and then read the data.

## Week 12 (2026-07-10 - 2026-07-16)

# Plans to do next
1. Get compass working and calibrate it
2. get rudder (yaw) working so plane would steer to next waypoint

# Outlook
1. get roll working so the plane stays level
2. get pitch working to stay level (with manual motor speed)
3. get pitch working to steer to desired altitude (with manual motor speed)
4. get automatic motor speed working
5. automatic landing

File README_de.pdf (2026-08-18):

## Auto Flight: Autonomes Segelflugzeug für Flächenabdeckungsflüge

Technische Dokumentation zur Projektaufgabe Embedded Systems

Tom Arlt, 1335730

18.08.2026

## Inhaltsverzeichnis

1 Einleitung | 1
2 Zielsetzung und Anwendungsszenario | 2
3 Anforderungen und Randbedingungen | 3
4 Systemarchitektur | 3
5 Technische Umsetzung und wesentliche Designentscheidungen | 11
6 Tests und Evaluation | 13
7 Bekannte Einschränkungen und mögliche Verbesserungen | 13
8 Individuelle Beiträge | 14

## 1 Einleitung

“Auto Flight” ist ein autonomes Segelflugzeug, das vordefinierte Flächen (z. B. landwirtschaftliche Felder) selbstständig in einem Mäandermuster abfliegt. Die Navigation erfolgt über eine Kombination aus GPS,

Beschleunigungssensor/Gyroskop (IMU), Magnetometer und Barometer. Das Flugzeug steht während des gesamten Flugs über eine Langstrecken-Funkverbindung (LoRa) mit einer Bodenstation in Kontakt, die eine Web-Oberfläche zur Missionsplanung und Live-Überwachung bereitstellt. Im Notfall kann das Flugzeug jederzeit über eine handelsübliche RC-Fernsteuerung manuell übernommen werden.

Das System besteht aus drei eigenständigen Firmware-/Software-Projekten (dem Flugcontroller im Flugzeug, der Bodenstation und einem Servo-/Motor-Controller) sowie einer Reihe geteilter Komponenten und Werkzeuge:

Projekt | Plattform | Aufgabe
flight_controller/ | ESP-IDF (ESP32-S3) | Hauptrechner im Flugzeug:
| | Routenplanung, Sensorik,
| | Flugregelung,
| | LoRa-Kommunikation
base_station/ | ESP-IDF (ESP32-S3) | Bodenstation:
| | WLAN-Zugangspunkt,
| | Web-UI-Server, LoRa-Relais
motor_controller/ | PlatformIO/Arduino
| (ATmega328) | Steuerflächen-
| | /Motoransteuerung,
| | SBUS-Empfang,
| | Sicherheits-Override
frontend_web/ | Vue 3 + TypeScript | Bedienoberfläche der
| | Bodenstation (Missionsplanung,
| | Live-Telemetrie)
shared_components/ | ESP-IDF-Komponenten | Gemeinsame Bausteine für
| | Flugcontroller und Bodenstation
| | (LoRa, I2C, Sensor-Treiber,
| | Datenhaltung)

Das Projekt ist eine studentische Einzelarbeit im Modul “Mobile Roboter” und befindet sich im Status eines fortgeschrittenen Prototyps. Ein fortlaufendes Entwicklungsprotokoll mit Fortschritt und aufgetretenen Problemen findet sich in resources/learning.md.

## 2 Zielsetzung und Anwendungsszenario

### 2.1 Grundidee

Ausgangspunkt des Projekts (siehe Projekt_Idee.md) ist ein autonomes Segelflugzeug, das definierte Flächen abfliegt. Die im Rahmen dieser Arbeit umgesetzte Version deckt den Beginn dieses Szenarios ab: die Kommunikation mit der Bodenstation, die Konfiguration und die Überwachung des Flugs. Das Flugzeug ist bereits in der Lage, aus der vorgegebenen Fläche eine Route zu berechnen und kleine Korrekturen während des Fluges auf Basis des Beschleunigungssensors vorzunehmen. Das Anfliegen der Route erfolgt jedoch noch nicht vollständig autonom, da die Höhenregelung und die Schubregelung noch nicht flugerprobt sind.

### 2.2 Anwendungsszenario

Das System ist für den Einsatz in der Kartografie und Landwirtschaft konzipiert. Bei einer Erweiterung um eine Kamera kann das System für die Inspektion von großen Flächen (z. B. landwirtschaftliche Felder, Solarparks, Wälder) genutzt werden. Die Bodenstation ermöglicht die Planung der zu überfliegenden Fläche, die Überwachung des Flugs und die Auswertung der Sensordaten. Das System ist für den Einsatz in ländlichen Gebieten mit geringer Bebauung und ohne Flugverbotszonen vorgesehen.

### 2.3 Bandbreiten- und Datenhaltungskonzept

Da LoRa bei großer Reichweite nur eine sehr geringe Bandbreite bietet, ist die Funkstrecke bewusst auf kompakte Status- und Steuerdaten (Position, Sensorwerte, Routen, Verbindungsstatus) beschränkt. Größere Nutzdaten wie Kamerabilder sind in der ursprünglichen Idee für eine lokale Speicherung (SD-Karte) oder eine WLAN-Übertragung nach der Landung vorgesehen und bewusst nicht Teil der LoRa-Strecke. Dieser Teil ist im aktuellen Funktionsumfang nicht umgesetzt, da keine Kamera-Nutzlast integriert wurde.

## 3 Anforderungen und Randbedingungen

### 3.1 Funktionale Anforderungen

- Autonome Navigation entlang eines aus einem benutzerdefinierten Polygon berechneten Streifenmusters (Wegpunktfolge)
- Bestimmung von Position, Lage (Roll/Pitch), Kurs (Heading) und Höhe während des Flugs aus GPS, IMU, Magnetometer und Barometer
- Fernkonfiguration der Zielfläche und Überwachung des Flugs über eine Weboberfläche, erreichbar über einen von der Bodenstation bereitgestellten WLAN-Zugangspunkt
- Telemetrieübertragung (Position, wichtige Sensordaten, Verbindungsstatus, Route) über eine Langstreckenfunkverbindung zwischen Flugzeug und Bodenstation
- Jederzeitige manuelle Übersteuerbarkeit der Steuerflächen und des Antriebs über eine RC-Fernsteuerung, unabhängig vom Zustand des Flugcontrollers

### 3.2 Nicht-funktionale Anforderungen und Randbedingungen

- Reichweite vs. Bandbreite: Die Funkstrecke muss auch über größere Entfernungen (Feldgröße) zuverlässig funktionieren. Das bedingt die Wahl von LoRa (868 MHz, ISM-Band) mit entsprechend geringer nutzbarer Datenrate und macht ein eigenes, sparsames Nachrichtenprotokoll notwendig (siehe Abschnitt “Technische Umsetzung”).
- Echtzeitfähigkeit: Die Flugregelung läuft mit einer festen Zykluszeit von 50 ms, um auf Lage- und Kursänderungen zeitnah reagieren zu können.
- Ressourcenbeschränkung: Als Segelflugzeug ist Gewicht ein limitierender Faktor für Akkukapazität, Sensorik und Servos. Das begrenzt sowohl die Rechenleistung (Mikrocontroller statt Einplatinencomputer) als auch die Anzahl gleichzeitig betreibbarer I2C-Sensoren an einem gemeinsamen Bus.
- Ausfallsicherheit: Die manuelle Übersteuerung darf nicht vom Zustand des Flugcontrollers abhängen, da dieser die eigentliche Ausfallquelle ist, gegen die abgesichert werden soll.
- Rechtlicher Rahmen: Im Projektverlauf wurde eine Recherche zu rechtlichen Rahmenbedingungen für autonome Fluggeräte durchgeführt (siehe Woche 2 in resources/learning.md), die insbesondere die Notwendigkeit einer jederzeit verfügbaren manuellen Kontrolle bestätigt.

### 3.3 Technische Randbedingungen

- Zwei baugleiche Heltec-WiFi-LoRa-32-V3-Boards (ESP32-S3 + integriertes SX1262-LoRa-Modul) als zentrale Rechen- und Funkeinheiten, eines im Flugzeug und eines in der Bodenstation
- Ein Arduino Nano (ATmega328) als separater, einfacher Servo-/Motor-Controller, angebunden über I2C an den Flugcontroller und über SBUS an den RC-Empfänger
- ESP-IDF (Version 5.x) als Firmware-Basis für Flugcontroller und Bodenstation, mit gemeinsam genutzten Komponenten in shared_components/
- Node.js/Vue 3 für die Weboberfläche, die als statische Dateien in den Flash-Speicher der Bodenstation eingebettet wird (kein separater Webserver)

## 4 Systemarchitektur

### 4.1 Hardwarearchitektur

### 4.1.1 Hauptkomponenten

Komponente | Einsatzort | Funktion
Heltec WiFi LoRa 32 V3 (ESP32-S3 + SX1262) | Flugzeug, Bodenstation (2×) | Hauptrechner +
| | LoRa-Funkmodul
Arduino Nano (ATmega328) | Flugzeug | Servo-/Motoransteuerung,
| | SBUS-Empfang,
| | Sicherheits-Override
GPS-Modul (ATGM336H, NMEA) | Flugzeug (Bodenstation optional) | Positionsbestimmung
MPU6050 (Beschleunigungssensor + Gyroskop) | Flugzeug | Lagebestimmung (Roll/Pitch)

Komponente | Einsatzort | Funktion
Magnetometer HMC5883L | Flugzeug | Kursbestimmung (Heading)
Barometer (BME280) | Flugzeug, Bodenstation | Höhenbestimmung über
| | Luftdruck
Level Shifter (3,3 V <-> 5 V) | Flugzeug | I2C-Pegelanpassung zwischen
| | ESP32-S3 (3,3 V) und Arduino
| | Nano (5 V)
Time-of-Flight-Sensor TOF200C | Flugzeug | Bodenabstandsmessung,
| | vorgesehen für die automatische
| | Landung
SBUS-Empfänger | Flugzeug | Empfang der
| | RC-Fernsteuerbefehle
4× Servo / ESC | Flugzeug | Querruder (differentiell),
| | Höhenruder, Schub, Seitenruder
LittleFS-Speicher | Bodenstation | Ablage der Web-UI-Dateien im
| | Flash
Akkus | Flugzeug, Bodenstation | Energieversorgung

Die vollständige Stückliste befindet sich in BOM.md. Der TOF200C-Abstandssensor ist Teil der Beschaffungsliste, aber im aktuellen Funktionsumfang noch nicht in die Firmware integriert, da die automatische Landung wie im Abschnitt “Bekannte Einschränkungen und mögliche Verbesserungen” beschrieben noch nicht umgesetzt ist.

Beim Magnetometer wurde ursprünglich ein QMC5883P eingesetzt und im Projektverlauf durch ein HMC5883L ersetzt. Beide zugehörigen Datenblätter liegen unter resources/ vor, der Grund für den Wechsel wird in Abschnitt “Technische Umsetzung und wesentliche Designentscheidungen” erläutert.

### 4.1.2 Schaltpläne

Die Schaltpläne für Flugzeug und Bodenstation wurden mit Fritzing (https://fritzing.org/) erstellt. Die Quelldateien liegen als assets/schematics_plane.fzz bzw. assets/schematics_base.fzz vor, zusammen mit selbst angelegten Fritzing-Bauteilen für Module ohne offizielle Fritzing-Unterstützung (BMP280-Breakout, GT-U8-GPS-Modul, Heltec WiFi Kit 32 (V3)).

Die Anbindung der 4 Servos wurde hier nicht im Schaltplan dargestellt, um die Übersichtlichkeit zu wahren. Die Servos werden direkt an den Arduino Nano angeschlossen, der die PWM-Signale erzeugt. Verwendet wurden die PWM-Pins 9, 10, 11 und 12 für Querruder links, Querruder rechts, Höhenruder und Seitenruder. Das Mapping zwischen Servo und Steuerfläche ist in der Regelung im ESP32-Flightcontroller festgelegt und kann bei Bedarf angepasst werden. Im Arduino Code gibt es ein festes Mapping: Byte 0 -> Servo 1, Byte 1 -> Servo 2, Byte 2 -> Servo 3, Byte 3 -> Servo 4. Welches Servo welcher Steuerfläche zugeordnet ist, wird dann in der Flugregelung im ESP32-Flightcontroller festgelegt.

Flugzeug:

Bodenstation:

### 4.1.3 Mechanischer Aufbau

Unter 3d_models/ liegen die 3D-gedruckten Gehäuse-/Montagekonstruktionen:

- Bodenstations-Gehäuse (base_station_case.scad): zweiteiliges Gehäuse (Wanne + Deckel) mit Snap-Fit-Verbindung, Aufnahmen für die Hauptplatine (Heltec LoRa32 V3 + GPS-Modul) und eine über Kabel angebundene Tochterplatine (Barometer), einer SMA-Antennendurchführung in der Gehäusewand sowie einem Druckausgleichsloch im Deckel oberhalb des Barometers.
- Flugzeug-Montageplatte (plane_mount_plate.scad): laut Kommentar im Quellcode ein reines Layout-Mockup, das die relative Anordnung von Hauptplatine, zwei Tochterplatinen und den vier Steuerflächen-Servos zeigt. Es ist ausdrücklich kein flugtaugliches Bauteil (keine Rumpfbefestigung, keine Kabelkanäle, keine Gewichtsoptimierung).

### 4.1.4 Systemtopologie

Die Steuerflächen können über die Servos sowohl vom Flugcontroller (über I2C) als auch direkt von der RC-Fernsteuerung (über SBUS) angesteuert werden. Welcher Pfad aktiv ist, entscheidet ausschließlich der

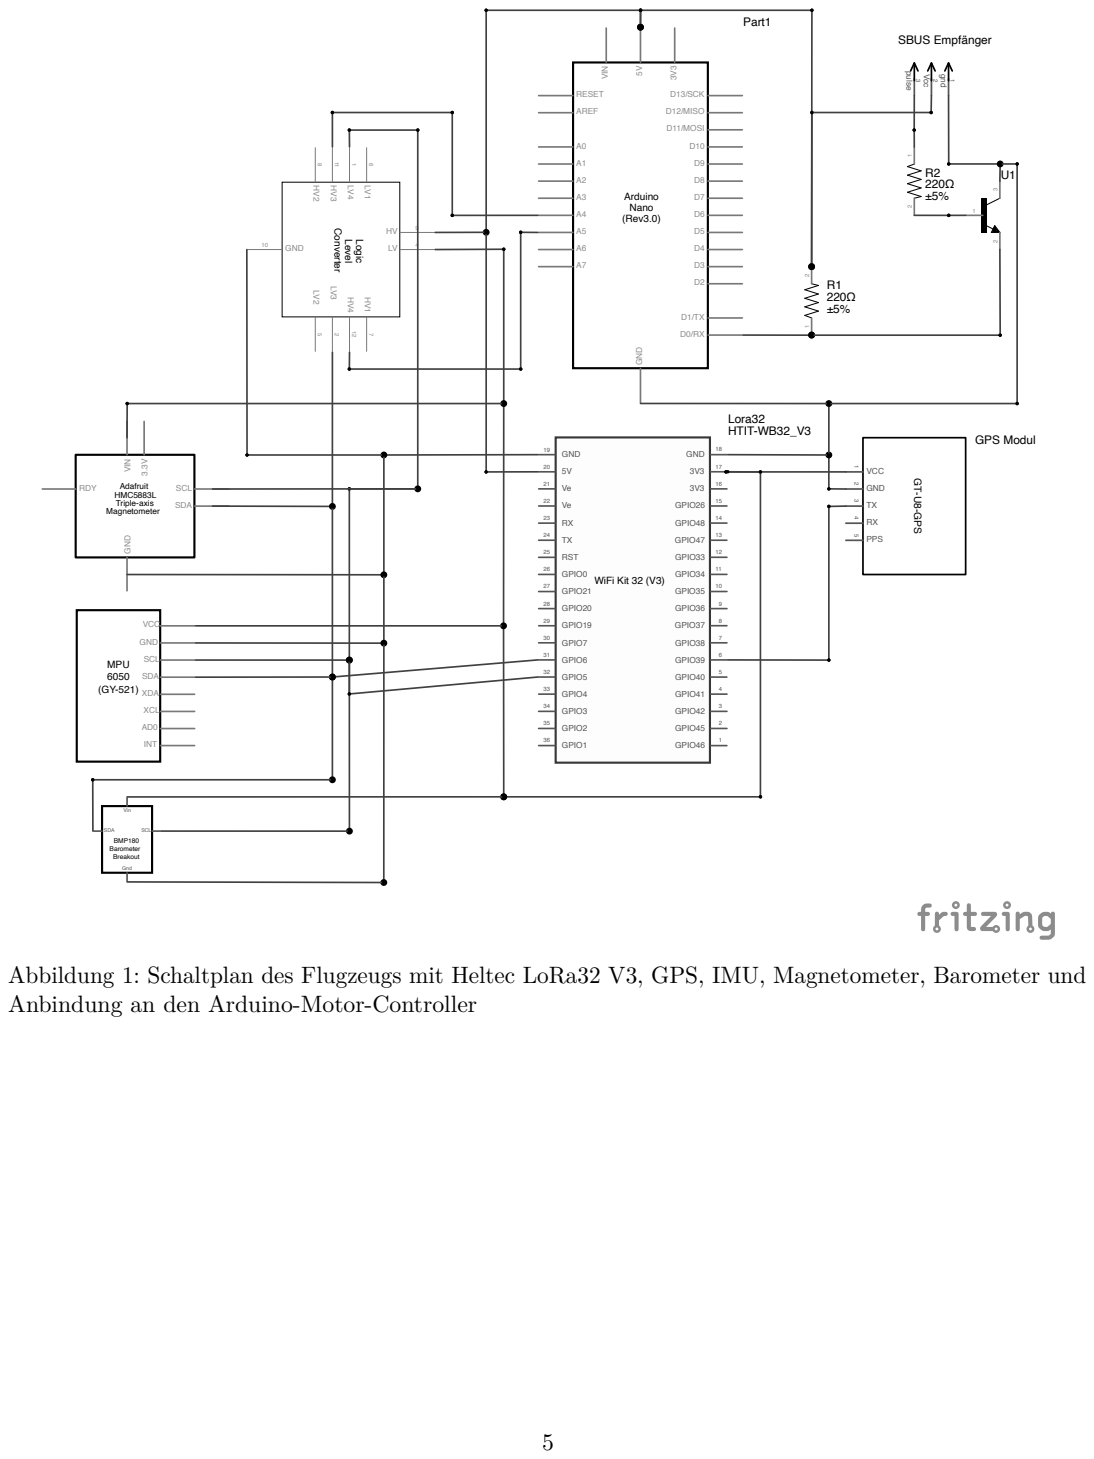
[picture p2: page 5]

Abbildung 1: Schaltplan des Flugzeugs mit Heltec LoRa32 V3, GPS, IMU, Magnetometer, Barometer und
Anbindung an den Arduino-Motor-Controller

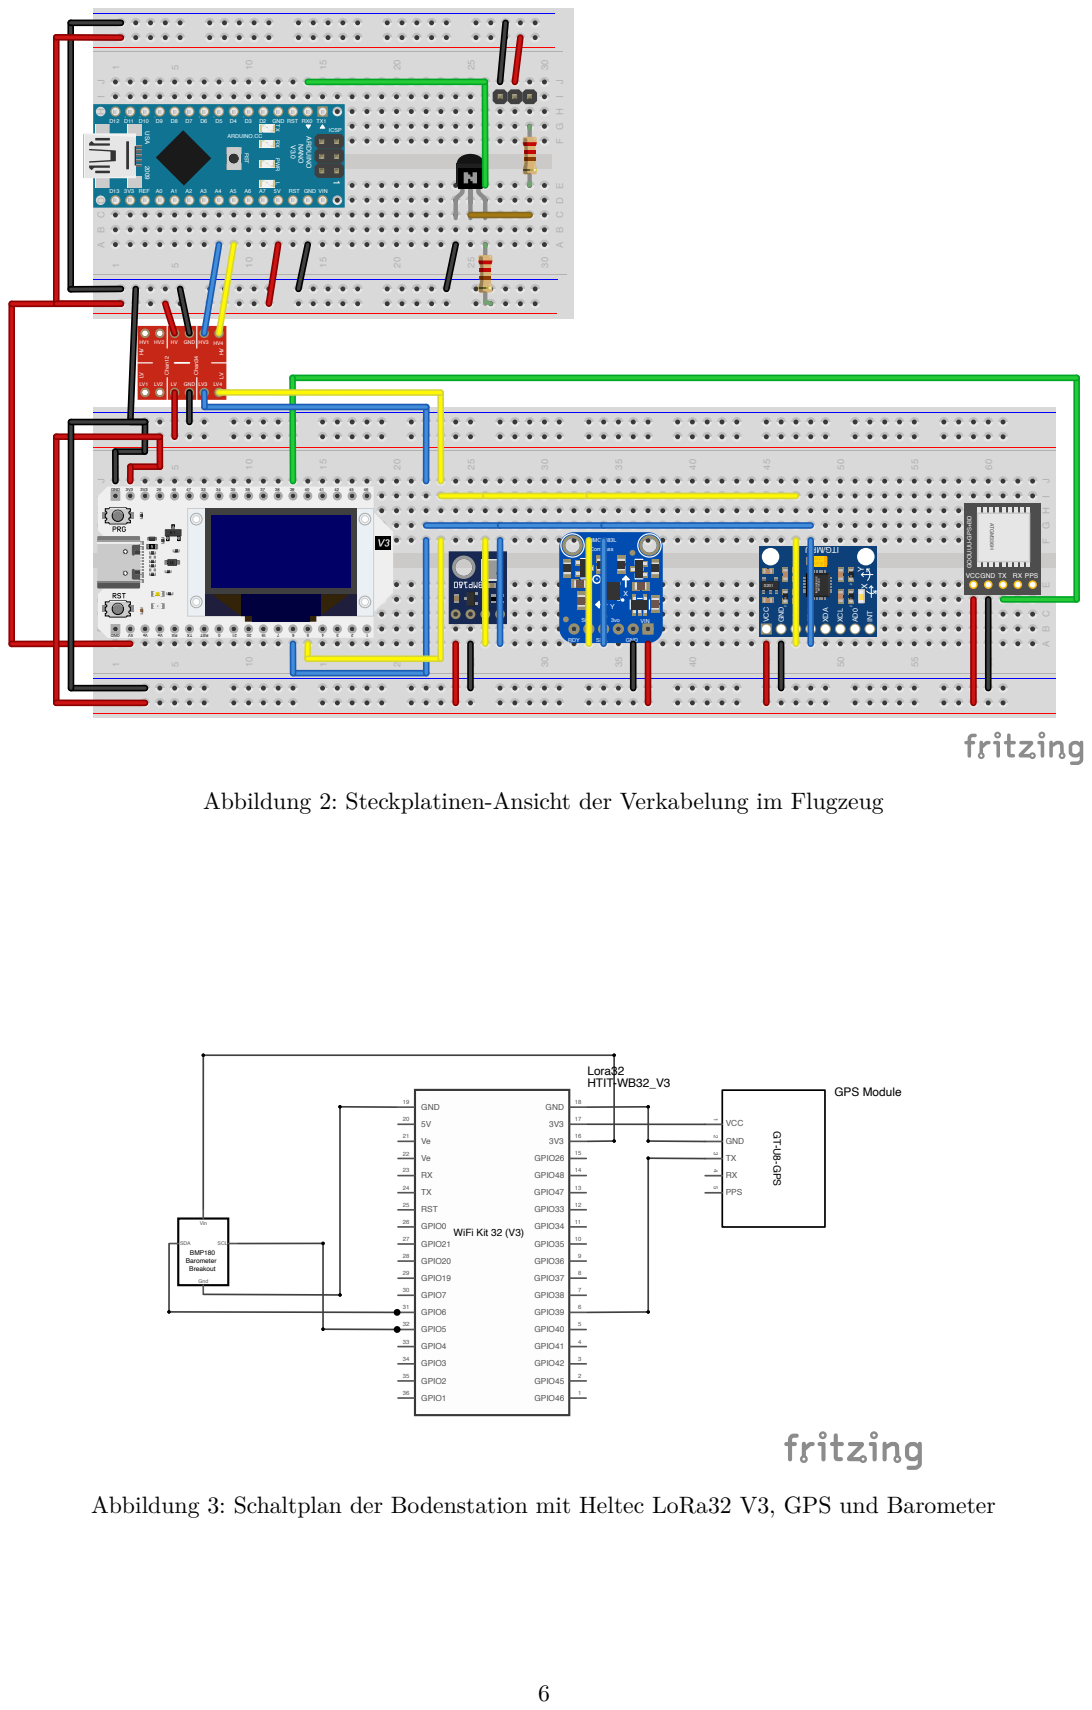
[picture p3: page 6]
GND; X Y VCC; SCL; SDA; XDA; XCL; AD⁰; INT; RDY; VIN; HMC5883L Compass; GNDD2D3; TX1RX0RST; D13 3V3 REF A0; RST GND VIN; 1 ICSP; RST; 2009USA; ARDUINO.CC; ARDUINO; NANO; HV GND; GNDLV; Chan12; Chan34; HVLV; 1 GPIO1; GPIO2; GPIO3; GPIO4; GPIO5; GPIO6; GPIO7; GPIO19; GPIO20; GPIO21; GPIO0; GPIO26; GPIO48; GPIO47; GPIO33; GPIO34; GPIO35; GPIO36; GPIO37; GPIO38; GPIO39; GPIO40; GPIO41; GPIO42; GPIO45; GPIO46; WiFi Kit 32 (V3); GT-U8-GPS; 1 VCC 2; GND 3; PPS; Gnd; Vin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

TX RX PWR

GOOUUU-GPS+BD VCCGND TX RX PPS ATGM336H

Abbildung 2: Steckplatinen-Ansicht der Verkabelung im Flugzeug

Abbildung 3: Schaltplan der Bodenstation mit Heltec LoRa32 V3, GPS und Barometer

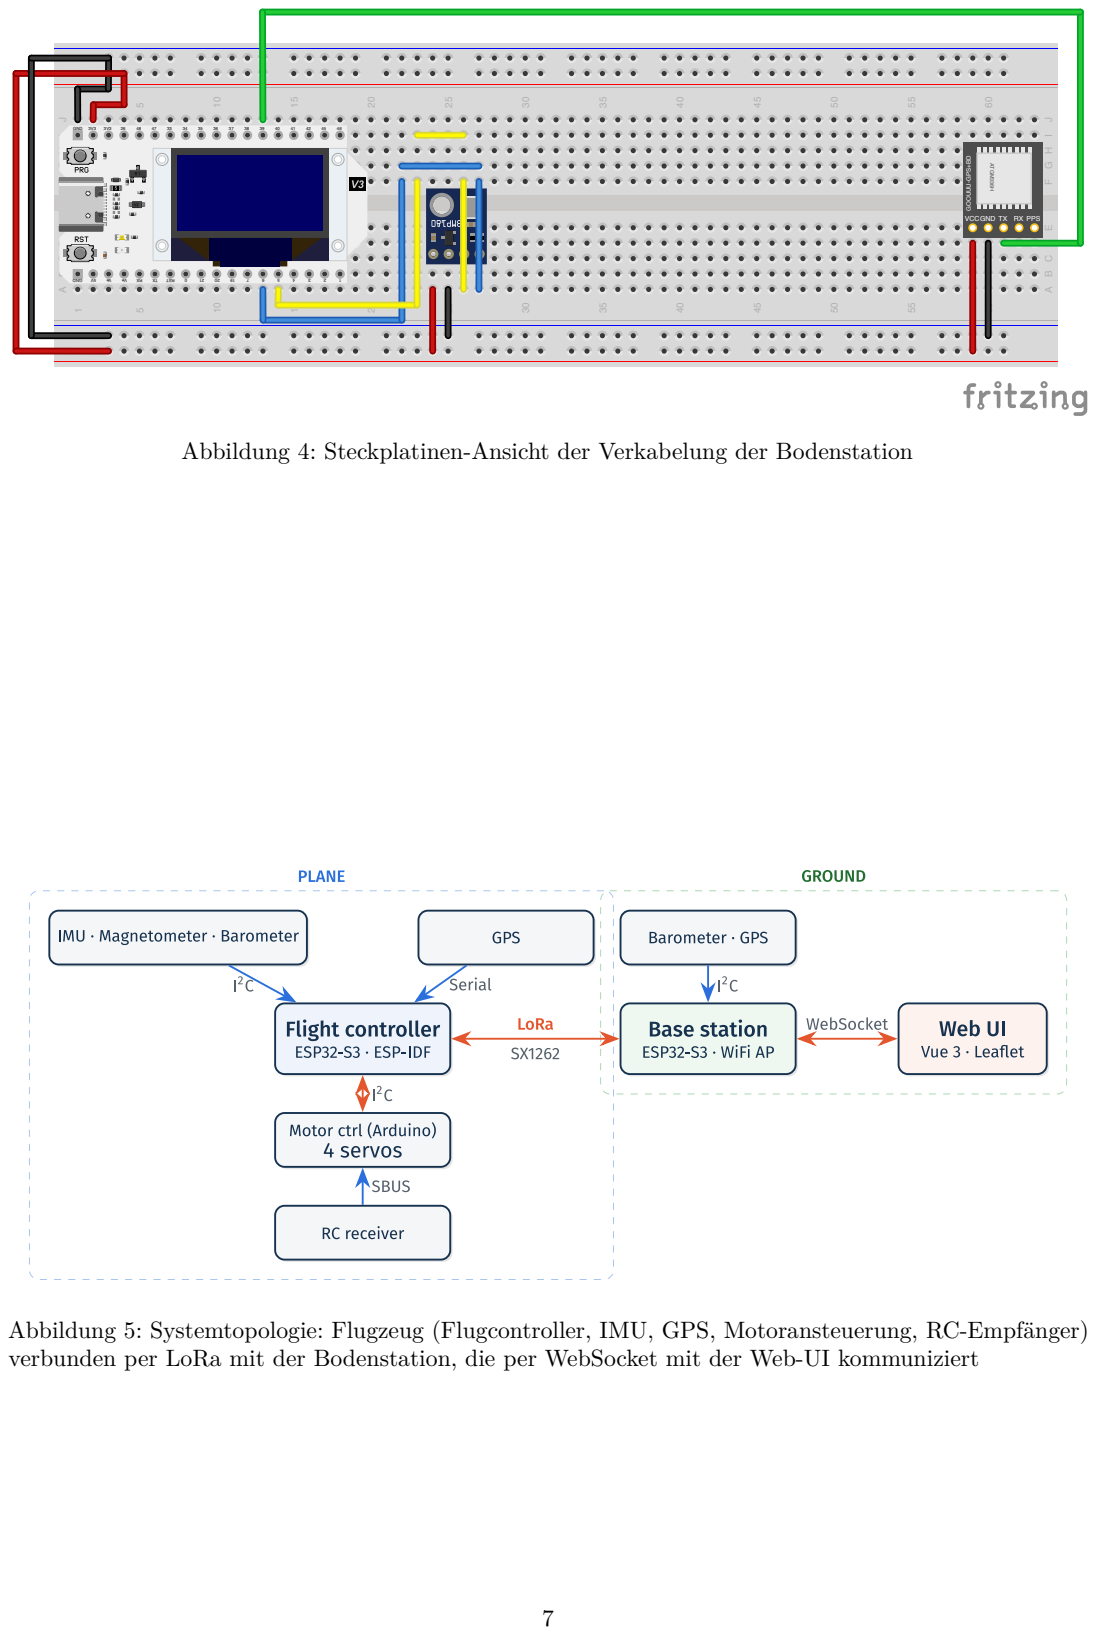
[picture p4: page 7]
GND

GOOUUU-GPS+BD VCCGND TX RX PPS ATGM336H

Abbildung 4: Steckplatinen-Ansicht der Verkabelung der Bodenstation

Abbildung 5: Systemtopologie: Flugzeug (Flugcontroller, IMU, GPS, Motoransteuerung, RC-Empfänger)
verbunden per LoRa mit der Bodenstation, die per WebSocket mit der Web-UI kommuniziert

Arduino im Flugzeug (siehe “Manuelle Übersteuerung”).

### 4.2 Softwarearchitektur

### 4.2.1 Projektstruktur

Pfad | Inhalt
flight_controller/ | ESP-IDF-Firmware des Flugzeugs: Routenplanung,
| Sensorik, Flugregelung, LoRa-Kommunikation
base_station/ | ESP-IDF-Firmware der Bodenstation: WLAN-AP,
| Web-UI-Server, LoRa-Relais
motor_controller/ | Arduino-Firmware für Servo-/SBUS-Anbindung
frontend_web/ | Vue-3-Weboberfläche der Bodenstation
shared_components/ | Zwischen Flugcontroller und Bodenstation geteilte
| ESP-IDF-Komponenten (LoRa, I2C,
| Sensor-Treiber, Datenhaltung)
python/ | Offline-Visualisierung der berechneten Flugrouten
serial_plane_viz/ | Werkzeug zur Visualisierung der Servo-Ausschläge
| über die serielle Schnittstelle
doc/, resources/ | Notizen, Pinouts, Datenblätter, Stückliste,
| Entwicklungsprotokoll

flight_controller und base_station sind zwei unabhängige ESP-IDF-Projekte mit jeweils eigener sdkconfig/CMakeLists.txt, die beide dieselben Komponenten aus shared_components/ über EXTRA_COMPONENT_DIRS einbinden. Das ist die zentrale Wiederverwendungsstrategie des Projekts: Sensor-Treiber, I2C-Verwaltung, der LoRa-Funkstack und das Anwendungsprotokoll existieren nur einmal und werden von beiden Firmware-Projekten geteilt, gesteuert über ein projektweites Compile-Flag (FLIGHT_DEVICE_TYPE_PLANE bzw. FLIGHT_DEVICE_TYPE_BASE_STATION), das jeweils festlegt, welche Rolle ein Gerät im Protokoll einnimmt. motor_controller ist ein eigenständiges Arduino-Projekt, das über I2C mit dem Flugcontroller kommuniziert und die Steuerflächen-Servos und den Motor ansteuert. Es ist bewusst einfach gehalten, da es nur die Aufgabe hat, die Servos zu bewegen und die SBUS-Signale der Fernsteuerung zu empfangen.

### 4.2.2 Kommunikationsschichten

Die Verbindung zwischen Flugzeug und Bodenstation ist in drei Schichten aufgeteilt:

1. Funkschicht (shared_components/lora_com): Ansteuerung des SX1262-Funkmoduls über die RadioLib-Bibliothek. Da ein LoRa-Paket auf 255 Byte begrenzt ist, implementiert diese Schicht eine eigene Fragmentierung größerer Nachrichten (Kopf mit Nachrichten-ID, Fragment-ID und Gesamtfragmentzahl), eine Bestätigung jedes Fragments per ACK mit Zeitüberschreitung (2 s) und bis zu drei Wiederholungsversuchen, sowie periodische Keep-Alive-Pings (Standard: alle 30 s), um die Verbindung zu überwachen, falls keine andere Nachricht gesendet wird.
2. Anwendungsprotokoll (shared_components/flight_com): definiert typisierte Pakete auf Basis der Funkschicht, u. a. SensorUpdate (Luftdruck, Kurs), PositionUpdate (GPS-Position), ComponentStatus (Verbindungszustand der einzelnen Subsysteme, Override-Status, Flugzustand), PlannedRoutePacket/PlannedAreaPacket (berechnete Route bzw. vorgegebene Fläche) und FlightHistoryPacket (geflogene Strecke).
3. Web-Anbindung (Bodenstation -> Browser): Die Bodenstation übersetzt die empfangenen LoRa-Pakete nicht direkt weiter, sondern schreibt sie in einen zentralen, thread-sicheren Zustandsspeicher (FlightStorage, Teil von shared_components/flight_data). Ein HTTP-/WebSocket-Server liest daraus und serialisiert die Daten getrennt als JSON für das Web-Frontend. LoRa-Format und Web-JSON-Format sind damit vollständig entkoppelt.

### 4.2.3 Web-Stack der Bodenstation

Die Bodenstation öffnet einen WLAN-AP (Standard-SSID, konfigurierbar über Kconfig, alternativ ein “Dev-Mode”, in dem stattdessen erst versucht wird, sich mit einem bestehenden WLAN zu verbinden) sowie einen HTTP-Server. Dieser bedient:

- Statische Dateien der Weboberfläche aus einer LittleFS-Flash-Partition (/*-Route als Fallback-Handler). Das Verzeichnis base_station/static ist ein Symlink auf frontend_web/dist, sodass ein Frontend-Build direkt als Flash-Image eingebunden wird (littlefs_create_partition_image in base_station/CMakeLists.txt).
- REST-API-Endpunkte: u. a. GET /api/status (Verbindungsstatus), POST/GET /api/area (Zielfläche setzen/lesen), GET /api/route (berechnete Route abfragen). Details siehe “API-Referenz der Bodenstation” unten.
- WebSocket-Endpunkt (GET /api/ws): sendet alle 5 Sekunden drei Nachrichtentypen an alle verbundenen Clients: flight (Positionen, geplante/geflogene Route), connection (Verbindungszustände aller Subsysteme), sensor (Luftdruck, berechnete Höhe, Kurs). Details siehe unten.

### 4.2.4 API-Referenz der Bodenstation

Sämtliche HTTP- und WebSocket-Endpunkte werden in der ESP-IDF-Komponente base_station/components/frontend registriert (FrontendHandlerClass::init()), nicht im base_controller. Beim Start wird zunächst
httpd_start aufgerufen, dann die LittleFS-Partition gemountet und anschließend werden die Handler
in fester Reihenfolge registriert: /api/ping, /api/ws, die übrigen REST-Endpunkte und zuletzt der
statische Datei-Handler /*. Diese Reihenfolge ist notwendig, da /* als Wildcard sonst alle spezifischeren Routen verdecken würde. Parallel dazu startet ein FreeRTOS-Task, der alle 5 Sekunden Status-Pakete via WebSocket verschickt.

### 4.2.4.1 Datentypen Alle Endpunkte tauschen JSON aus, das per nlohmann::json direkt

aus den C++-Strukturen in FrontendPackets.hpp (de-)serialisiert wird. Die Typen im Frontend (frontend_web/src/types/) bilden dieselben Strukturen in TypeScript nach:

type Coordinate = { longitude: number; latitude: number }
type Route = Coordinate[]
type ConnectionState = "connecting" | "connected"
type FlightState = "planning" | "planned" | "flying" | "returning"

interface AreaDefinePacket {
shape: Coordinate[]
}

interface PlannedRoutePacket { type: "plannedRoute"
route: Coordinate[]
}

interface ConnectionUpdatePacket {
type: "connection"
baseConnectionState: ConnectionState lastContactBaseStationTimestamp: number planeConnectionState: ConnectionState lastContactPlaneTimestamp: number gpsConnectionBase: ConnectionState gpsConnectionPlane: ConnectionState barometerConnectionBase: ConnectionState barometerConnectionPlane: ConnectionState motorComConnectionPlane: ConnectionState magnetometerConnectionPlane: ConnectionState accelerometerConnectionPlane: ConnectionState manualOverridePlane: boolean
flightState: FlightState
}

interface FlightUpdatePacket { type: "flight"
basePosition: Coordinate
basePositionUpdateTime: number

planePosition: Coordinate
planePositionUpdateTime: number flightRoute: Route
flightRouteUpdateTime: number plannedRoute: Route
plannedRouteUpdateTime: number }

interface SensorUpdatePacket { type: "sensor"
barometerPressureBase: number barometerPressurePlane: number calculatedAltitude: number headingPlane: number
}

...Timestamp/...UpdateTime-Felder sind Unix-Zeitstempel, die entweder aus der Laufzeit oder aus dem GPS-Signal stammen. ConnectionState/FlightState werden als Strings statt Zahlen serialisiert.

### 4.2.4.2 Endpunkte

Methode | Pfad | Funktion | Typ
GET | /api/ping | Liveness-Check | Text "pong"
GET | /api/ws | WebSocket-Upgrade,
| | Live-Telemetrie | siehe unten
GET | /api/status | Verbindungs- und
| | Flugzustand | ConnectionUpdatePacket
POST | /api/area | Zielfläche setzen | Body:
| | | AreaDefinePacket
GET | /api/area | Zielfläche abfragen | AreaDefinePacket
GET | /api/route | Berechnete Route
| | abfragen | PlannedRoutePacket
GET | /* | Statische
| | Web-UI-Dateien aus
| | LittleFS | —

WebSocket /api/ws Nach dem Upgrade wird der Client registriert und alle 5 Sekunden mit drei Nachrichten versorgt, unterschieden über type: FlightUpdatePacket, ConnectionUpdatePacket, SensorUpdatePacket (Typdefinitionen siehe oben). Sendet ein Client die Textnachricht "ping", antwortet der Server mit "pong" (im Frontend als Verbindungs-Heartbeat genutzt). Der Typ der WebSocket-Nachricht wird aktuell über das erste Feld type im JSON-Objekt unterschieden, nicht über die WebSocket-Subprotokoll-Mechanismen.

### 4.2.5 Frontend

Die Weboberfläche (frontend_web/) ist eine Vue-3-/TypeScript-Single-Page-Anwendung, gebaut mit Vite. Sie führt den Bediener über einen Assistenten durch die Missionsvorbereitung:

- Verbindungsübersicht: zeigt den Live-Status von Basis- und Flugzeugverbindung sowie deren Teilsysteme (GPS, Barometer, Motoransteuerung, Magnetometer) und gibt den nächsten Schritt erst frei, wenn alle Verbindungen stehen.
- Flächenplanung: Zeichnen eines Zielpolygons auf einer Leaflet-Karte (über leaflet-draw), Übertragung an die Bodenstation.
- Routenvorschau: Abfrage der vom Flugzeug berechneten Route, Darstellung auf der Karte zusammen mit der bisher geflogenen Strecke.
- Live-Telemetrie: laufende Aktualisierung von Position, Route und Sensorwerten über die WebSocket-Verbindung, ergänzt um einen eigenen Ping/Pong-Herzschlag im Frontend zur Erkennung von Verbindungsabbrüchen.

## 5 Technische Umsetzung und wesentliche Designentscheidungen

### 5.1 Routenplanung

Der route_planner erzeugt aus einem vom Bediener gezeichneten Polygon ein Mäander- bzw. Boustrophedon-Muster:

1. Sweep-Lines erzeugen: Aus der Bounding-Box des Polygons werden äquidistante, horizontale Linien (parallel zum Breitengrad) im Abstand der effektiven Schwadbreite berechnet.
2. Zuschneiden auf das Polygon: Jede Linie wird mit dem tatsächlichen, auch konkaven, Polygon geschnitten (Geometriebibliothek homog2d). (https://github.com/skramm/homog2d) Bei mehreren Schnittpunkten wird nur das äußere Segment behalten, sodass Löcher und konkave Formen korrekt ausgespart werden.
3. Pfad zusammensetzen: Die einzelnen Linien werden abwechselnd von links nach rechts bzw. rechts nach links zu einem durchgehenden Pfad verbunden. Zwischen zwei Zeilen werden zusätzliche Zwischenpunkte eingefügt, um statt einer scharfen 180°-Kehre eine weichere Kurvenbahn zu erzeugen.
4. Interpolation: Abschließend werden alle Teilstrecken, die länger als ein konfigurierter Maximalabstand sind, in gleichmäßige Zwischenpunkte unterteilt, sodass zwei aufeinanderfolgende Wegpunkte nie weiter als dieser Abstand auseinanderliegen. Diese Interpolation sollte später für die Kamerasteuerung verwendet werden können und ist nicht nur für die Flugregelung relevant.

In der aktuellen Implementierung ruft der Flugcontroller die Routenplanung mit einer maximalen Punktdistanz von 60 m, einer Schwadbreite von 40 m und einem Überlappungsfaktor von 20 % auf, was einem effektiven Zeilenabstand von 32 m entspricht. Diese Werte sind aktuell im Quellcode fest hinterlegt und nicht konfigurierbar. Für die spätere Integration einer Kamera würde dies mit der effektiven Bildbreite/FOV der Kamera, der Flughöhe und einer gewünschten zusätzlichen Überlappung zwischen den Bildern in Beziehung gesetzt werden, um die Parameter für die Routenplanung zu bestimmen.

### 5.2 Flugregelung

Der Flugcontroller (FlightController) läuft als FreeRTOS-Task mit einem festen Zyklus von 50 ms und implementiert eine kaskadierte PI-Regelung für vier Steuergrößen:

- Seitenruder (Kurs): Aus der aktuellen GPS-Position und dem nächsten Wegpunkt wird die Soll-Peilung (Bearing) berechnet und mit dem gemessenen Kompasskurs verglichen. Der normalisierte Peilungsfehler wird proportional (P-Regelung) auf das Seitenruder abgebildet.
- Höhenhaltung: Die Differenz aus Zielhöhe (60 m) und gemessener Höhe treibt zwei parallele PI-Regelungen: eine für den Schub und eine für den Ziel-Pitch-Winkel, der wiederum als Sollwert in die Nickregelung einfließt (kaskadierte Regelung).
- Querruder: Reine “Wings-Level”-Regelung (PI auf den Rollwinkel), unabhängig vom Kurvenkommando. Es gibt aktuell keine koordinierte Kurve, das Abbiegen erfolgt ausschließlich über das Seitenruder.
- Höhenruder: PI-Regelung des Nickwinkels auf den von der Höhenregelung vorgegebenen Ziel-Pitch.

Die Wegpunkt-Erreichung wird über den Abstand zur aktuellen Position gegen einen konfigurierbaren Radius (Standard 30 m) geprüft. Ist der letzte Wegpunkt erreicht, wechselt der interne Flugzustand auf “Rückkehr”. In der bisherigen Implementierung hat dies aber noch keinen Effekt. Reglerverstärkungen und Zielhöhe sind, anders als zum Beispiel Telemetrieintervall oder Wegpunktradius, als Konstanten im Quellcode hinterlegt statt als Kconfig-Parameter.

### 5.3 Sensorik und Datenfusion

Die Sensordatenverarbeitung ist bewusst einfach gehalten: Es kommt kein gemeinsamer Zustandsschätzer zum Einsatz. Stattdessen wird jeder abgeleitete Messwert unabhängig über ein gleitendes Mittel geglättet und direkt in die jeweilige PI-Regelung eingespeist:

- Lage (Roll/Pitch): wird ausschließlich aus der Schwerkraftrichtung des Beschleunigungssensors berechnet (atan2 über die Beschleunigungskomponenten), nach einer Nullpunktkalibrierung beim Start.
- Kurs (Heading): wird direkt aus den Magnetometer-Rohwerten berechnet (atan2), ohne Neigungskompensation gegenüber Roll/Pitch und ohne Korrektur der magnetischen Missweisung. Anschließend wird der Wert zirkulär geglättet (getrennte Mittelung von Sinus-/Kosinuskomponenten, um den Sprung bei 0°/360° korrekt zu behandeln).
- Höhe: aus dem barometrischen Luftdruck über die hydrostatische Grundgleichung, bezogen auf einen von der Bodenstation übermittelten Referenzdruck am Boden. Die berechnete Höhe ist somit relativ zum Startpunkt (AGL) und nicht absolut (MSL).
- Position: direkt aus geparsten GPS-NMEA-Sätzen, ohne zusätzliche Filterung oder Koppelnavigation. Eine Position gilt erst ab einer Mindestanzahl empfangener Satelliten als gültig.

Diese Architektur ist als pragmatischer Zwischenstand zu verstehen. Sie liefert brauchbare, aber gegenüber Vibrationen und kurzfristigen Störungen empfindlichere Schätzwerte als eine echte Sensorfusion (siehe “Bekannte Einschränkungen”).

### 5.4 Kommunikation Flugcontroller / Motor-Controller

Der Arduino-Motor-Controller ist I2C-Slave (Adresse 0x42) mit einem bewusst minimalen, registerlosen Protokoll:

- Schreiben (Flugcontroller → Arduino): genau 4 Byte, je ein vorzeichenbehafteter Wert im Bereich -100. . . 100 für Seitenruder, Höhenruder, Schub und differentielles Querruder. Unvollständige Übertragungen werden verworfen. Die zuletzt gültigen Werte bleiben erhalten.
- Lesen (Arduino → Flugcontroller): ein einzelnes Statusbyte, das anzeigt, ob der manuelle Override aktiv ist. Ein erfolgreicher Lesevorgang dient gleichzeitig als Verbindungsprüfung.

Der Arduino überwacht selbstständig die Aktualität eingehender I2C-Nachrichten und initialisiert den I2C-Bus automatisch neu, wenn eine Sekunde lang keine Nachricht eintrifft. Das ist eine Absicherung gegen hängende Bus-Zustände, die im Projektverlauf mehrfach beobachtet wurden.

### 5.5 Manuelle Übersteuerung

Die sicherheitskritische Entscheidung, ob das Flugzeug autonom oder manuell gesteuert wird, ist bewusst nicht im Flugcontroller, sondern wird auf dem Arduino getroffen. Ein festgelegter SBUS-Kanal (Kanal 5) des RC-Empfängers wird als Override-Schalter interpretiert. Überschreitet sein Wert den Schwellwert von 1500 µs (Neutralstellung), steuert der Arduino die vier Servos direkt aus den SBUS-Kanälen an und ignoriert die zuletzt vom Flugcontroller empfangenen I2C-Werte. Der Flugcontroller selbst liest den Override-Status nur zu Anzeige-/Telemetriezwecken mit, hat aber keinen Einfluss darauf. Diese Entkopplung stellt sicher, dass die manuelle Kontrolle auch bei einem Absturz oder Hänger der ESP32-Firmware erhalten bleibt. Im aktuellen Aufbau wurde der SBUS Empfänger MRFS01 von Futaba verwendet (Link zu Aliexpress). (https://de.aliexpress.com/item/1005007253167246.html) Der SBUS Empfänger übermittelt die Steuerbefehle über eine Serielle Schnittstelle (UART) an den Arduino, jedoch wurde von Futaba eine spezielle Konfiguration der UART Schnittstelle verwendet. DIe Arduino Bibliothek SBUS (https://github.com/george-hawkins/arduino-sbus) unterstützt diese Konfiguration, mit ein paar Hardware Anpassungen für den Arduino Nano. Der Futaba SBUS Empfänger kommuniziert über eine invertierte UART Schnittstelle mit 100000 Baud, 8 Datenbits, 2 Stopbits und gerader Parität. Der Arduino Nano hat jedoch keine invertierte UART Schnittstelle, daher wurde mithilfe eines 2N2222 Transistors eine Invertierung der UART Signale realisiert. Die Schaltung ist in der Schaltplan Datei schematics_plane.fzz oder im Kapitel Schaltpläne zu finden.

### 5.6 Wesentliche Designentscheidungen im Projektverlauf

- Wechsel von PlatformIO zu ESP-IDF für Flugcontroller und Bodenstation (Woche 4 des Entwicklungsprotokolls): Auslöser waren Schwierigkeiten in der Komponentenverwaltung unter PlatformIO. ESP-IDF ermöglichte zudem, dieselben Komponenten nativ auf dem Host-Rechner zu bauen und zu testen (siehe “Tests und Evaluation”).
- Wechsel des Magnetometers von QMC5883P auf HMC5883L sowie Umstellung des Auslesemodus von “Continuous” auf “Single-Read” (Wochen 10 und 11): Das ursprünglich verbaute QMC5883P antwortete unzuverlässig und teils unter wechselnden I2C-Adressen. Die tiefere Ursache eines wiederkehrenden Bus-Ausfalls wurde später identifiziert: Im kontinuierlichen Messmodus kann ein Lesezugriff während einer laufenden internen Messung den Sensor in einen Zustand versetzen, der den gesamten I2C-Bus blockiert bzw. mit Stördaten belegt, statt nur einen einzelnen fehlerhaften Messwert zu liefern. Die Umstellung auf einzeln angeforderte Messungen (Single-Read) behebt dieses Verhalten, da der Sensor Lesezugriffe erst nach Abschluss einer Messung zulässt.
- Eigenes Fragmentierungsprotokoll über LoRa: Da einzelne Anwendungsnachrichten (z. B. eine vollständige geplante Route) die maximale LoRa-Paketgröße von 255 Byte überschreiten können, wurde ein eigenes Fragmentierungs- und Bestätigungsschema mit Nachrichten-/Fragment-IDs, inspiriert von TCP, entwickelt.
- Trennung von Funkprotokoll und Web-Protokoll: Die bewusste Entkopplung von LoRa-Wireformat und WebSocket-/REST-JSON-Format über den zentralen FlightStorage-Zustandsspeicher erlaubt es, beide Seiten unabhängig voneinander weiterzuentwickeln.

### 5.7 Begleitende Werkzeuge

Zwei Werkzeuge unterstützen die Entwicklung, sind aber nicht Teil der eigentlichen Flugsoftware:

- python/: Zwei kleine Skripte zur Offline-Visualisierung der vom Routenplaner erzeugten Sweep-Pfade, als einfacher 2D-Plot (matplotlib) oder auf einer interaktiven Karte (folium).
- serial_plane_viz/: Ein Browser-Werkzeug (three.js), das Servo-Ausschläge (Motor, Roll, Pitch, Yaw), die über eine serielle Schnittstelle im selben Wertebereich wie das I2C-Protokoll des Motor-Controllers gesendet werden, an einem einfachen 3D-Flugzeugmodell visualisiert. Das ist nützlich zur Fehlersuche ohne reales Flugzeug.

## 6 Tests und Evaluation

### 6.1 Automatisierte Tests

Flugcontroller (native Unit-Tests): Das Build-System von flight_controller unterscheidet anhand einer Umgebungsvariable zwischen einem echten ESP-IDF-Firmware-Build und einem nativen Host-Build. Für Letzteren existiert ein eigener CMake-Kompatibilitäts-Layer, der ESP-IDF-Komponenten als gewöhnliche CMake-Bibliotheken für den Host kompilierbar macht, sodass die Geschäftslogik ohne reale Hardware getestet werden kann (GoogleTest). Inhaltlich beschränken sich die vorhandenen Tests ausschließlich auf die Geometrie der Routenplanung: korrekte Erkennung der äußeren Polygonpunkte, korrekte Schnittpunktberechnung zwischen Linie und Polygon, korrekte Anzahl/Lage der erzeugten Sweep-Lines sowie ein monotoner Verlauf des zusammengesetzten Sweep-Pfads. Es existieren keine automatisierten Tests für die Flugregelung (PI-Regler), die Sensor-Treiber oder das I2C-Protokoll zum Motor-Controller. Dieser Teil wird ausschließlich auf echter Hardware verifiziert.

Frontend: Typprüfung (vue-tsc) und Linting (ESLint/oxlint) laufen als Basis-Qualitätssicherung bei jedem Build. Ein Playwright-E2E-Grundgerüst ist eingerichtet. Der einzige vorhandene Test ist jedoch der unveränderte Gerüst-Test der Vue-Projektvorlage; reale Tests, die tatsächliche Funktionalität abdecken, wurden aufgrund der stetigen Veränderungen und Erweiterungen der Anwendung bisher nicht implementiert.

### 6.2 Evaluation anhand des Entwicklungsverlaufs

Das Entwicklungsprotokoll (resources/learning.md) dokumentiert den Fortschritt über zwölf Wochen und erlaubt eine ehrliche Einschätzung des tatsächlich erreichten Funktionsstands:

- Erfolgreich umgesetzt und in Betrieb genommen wurden: GPS-Auswertung, eine funktionierende LoRa-Verbindung mit Bestätigungen und Keep-Alive-Pings, die I2C-Anbindung von Barometer und IMU sowi e, nach den beschriebenen Hardware-Problemen, eine funktionsfähige Magnetometer-Anbindung.
- Mehrere grundlegende technische Probleme mussten während der Entwicklung gelöst werden, u. a. eine notwendige Paketfragmentierung für LoRa-Nachrichten über 255 Byte, ein Deadlock in der Event-Handler-Warteschlange sowie die oben beschriebenen I2C-Bus-Aussetzer im Zusammenhang mit dem Magnetometer.
- Wiederkehrende I2C-Bus-Instabilität beim gleichzeitigen Betrieb mehrerer Sensoren am selben Bus war das am längsten offene Hardware-/Firmware-Problem im Projektverlauf und ist auch bei den implementierten Workarounds (Bus-Recovery, Single-Read-Modus) als grundsätzliches Restrisiko zu betrachten.

## 7 Bekannte Einschränkungen und mögliche Verbesserungen

Sensorfusion: Die Lagebestimmung erfolgt rein aus dem Beschleunigungssensor, ein Kalman- bzw. Komplementärfilter ist nicht aktiv, und der Kompass arbeitet ohne Neigungskompensation bzw. Deklinationskorrektur. Als Verbesserung sollten der vorhandene Komplementärfilter und die Gyroskop-Integration tatsächlich in die Regelschleife eingebunden sowie Neigungskompensation und Deklination im Heading ergänzt werden.

Regelung: Reglerverstärkungen und Zielhöhe sind hartkodiert statt konfigurierbar, es gibt keine koordinierte Kurve (Querruder unabhängig vom Kurvenkommando), und die volle Regelkaskade ist nicht flugerprobt. Verbessern ließe sich dies, indem die Gains über Kconfig bzw. zur Laufzeit konfigurierbar gemacht werden, systematische Flugtests durchgeführt werden und eine koordinierte Kurvenregelung ergänzt wird.

Missionsparameter & Konfigurierbarkeit: Schwadbreite, Überlappungsfaktor und maximale Punktdistanz sind für die Routenplanung fest im Quellcode hinterlegt (siehe Abschnitt “Routenplanung”) und nicht konfigurierbar, um sie auf unterschiedliche Kameras (FOV, Modell), Akkukapazitäten oder Flugzeuggrößen/-gewichte abzustimmen; ebenso fehlt jegliche Konfiguration für den koordinierten Betrieb mehrerer Flugzeuge (Schwarmkonfiguration). Sinnvoll wäre es, diese Missionsparameter über die Weboberfläche konfigurierbar zu machen und die Kommunikations-/Adressierungsschicht (siehe “Funkstrecke”) so zu erweitern, dass mehrere Flugzeuge und Basisstationen als Schwarm koordiniert werden können.

Pfadplanungsalgorithmen: Aktuell ist ausschließlich ein Sweep-Line-Mäandermuster implementiert; alternative Coverage-Path-Planning-Algorithmen wurden nicht durchgetestet oder evaluiert. Eine systematische Evaluation verschiedener Algorithmen anhand von Flugstrecke, theoretischer Flugdauer und geschätzter Akkukapazität stünde noch aus und wäre ein sinnvoller nächster Schritt, um die Routenplanung über die reine Geometrie hinaus energie- und laufzeitbewusst zu machen.

Hardware-Robustheit: Bei mehreren angeschlossenen Sensoren treten wiederkehrende I2C-Bus-Aussetzer auf, die trotz Workarounds ein Restrisiko darstellen. Als Verbesserung bietet sich an, die Bus-Topologie zu überdenken (z. B. I2C-Multiplexer, getrennte Busse) und ein Hardware-Redesign der Verkabelung vorzunehmen.

Funkstrecke: Es ist keine Verschlüsselung aktiv, es gibt keine Geräteadressierung (nur Punkt-zu-Punkt, relevant für mehrere Flugzeuge/Basisstationen), und die Sendezeit-Regelung ist nicht kontrolliert. Verbesserungspotenzial liegt in der Aktivierung von Verschlüsselung, der Ergänzung einer Adressierung für Mehrflugzeug-Szenarien und der Implementierung einer Kontrolle der maximalen Sendezeit.

Testabdeckung: Nur die Routenplanungs-Geometrie ist automatisiert getestet, die CI baut ausschließlich die Dokumentation und nicht die Firmware bzw. das Frontend, und der Frontend-E2E-Test ist unveränderter Gerüst-Code. Hier sollten Unit-Tests für Regelungslogik und Protokollcode ergänzt, Firmware-/Frontend-Build und Tests in die CI-Pipeline aufgenommen und der Playwright-Test an die reale Anwendung angepasst werden.

Frontend-Code: Das Frontend ist noch nicht fertiggestellt. Es fehlen noch Möglichkeiten zur weiteren Konfiguration der Flugstreckenberechnung, die Flugüberwachung, sobald der Flug gestartet wurde, sowie ein Return-to-Home. Aktuell gibt es auch noch ein Problem mit dem Laden der Tiles für die OpenStreetMap-Karte. Da sich das Endgerät im WLAN der Basisstation befindet und diese keinen Internetzugriff bietet, funktioniert die Kartenansicht aktuell nur, wenn ein eigener Hotspot aufgemacht wird oder man zwischenzeitig auf mobile Daten wechselt, um die Karte zu laden. Als Lösung für dieses Problem bietet sich ein SIM-Modul an. Alternativ wäre der Wechsel zu einer nativen App mit Kommunikation per Bluetooth eine elegante Variante, die es ermöglichen würde, die Offline-Karten des Mobiltelefons zu verwenden.

Flugtests: Es wurden keine echten Flugtests durchgeführt, da Höhenregelung und Schubregelung noch nicht adäquat implementiert sind; zudem sind die bisherigen Servo-Regelungen noch zu kontrollieren. Als nächster Schritt sollten systematische Flugtests durchgeführt werden, ggf. mit Sicherheitsleine oder in einem abgesperrten Testbereich.

Kameraeinbindung: Bisher wurde die Kamera in diesem Prototypen außen vor gelassen. Die Bildabdeckung ist zwar über FOV und Bodendistanz berechenbar, eine zuverlässige Bodendistanzmessung fehlt aber noch: Barometer und GPS liefern nur die Höhe über Startpunkt/Meeresspiegel und versagen in hügeligem bzw. bergigem Gelände ohne begleitende Höhenkarte, ein LiDAR-Sensor für Reichweiten über 40 m wäre hierfür ebenfalls noch zu ergänzen. Für eine Bildverarbeitung existiert die Idee der Feuer-/Raucherkennung. Hierfür könnte versucht werden, auf einem ESP ein kleines quantisiertes CNN laufen zu lassen (inspiriert von dem Projekt ESP32 LLM). (https://github.com/DaveBben/esp32-llm) Als naive, ressourcenschonendere Alternative dazu käme ein einfacher heuristischer Algorithmus in Frage (z. B. Grau-/Rotanteil im Bild, optional unterstützt durch eine Wärmebildkamera). Nächste Schritte wären die Anbindung einer echten Kamera an diesen ESP32-Prototypen, die Integration in den Gesamtprozess (Flugcontroller/Bodenstation) sowie ein vergleichender Test beider Ansätze (naiv vs. CNN) hinsichtlich Erkennungsgüte und Ressourcenverbrauch.

## 8 Individuelle Beiträge

Das Projekt wurde als Einzelarbeit umgesetzt (ein Autor laut Aufgabenstellung und Versionskontrolle). Konzeption, die gesamte Firmware-Entwicklung (Flugcontroller, Bodenstation, Motor-Controller), die Entwicklung der Weboberfläche, die Auswahl und Integration der Hardware sowie diese Dokumentation stammen vollständig von derselben Person. Eine Aufteilung auf mehrere Bearbeiter entfällt entsprechend. Es wurden in kleinem Maße KI-Tools zur Unterstützung beim Refactoring oder bei der Entwicklung der 3D-Visualisierung genutzt. Die wesentlichen Teile der Softwareentwicklung, insbesondere auch das Systemdesign, die Systemstruktur und die Systemlogik, wurden jedoch ohne KI umgesetzt.

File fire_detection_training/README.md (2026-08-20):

# Fire/Smoke CNN Training

Trains a small image classifier (fire / smoke / none) and exports it as an
int8-quantized TensorFlow Lite model, ready to embed into the
[`fire_detection_esp`](../fire_detection_esp) ESP-IDF project.

## Pipeline

```
data/raw/<class>/*.jpg
        │  prepare_dataset.py
        ▼
data/{train,val,test}/<class>/*.jpg
        │  train.py
        ▼
models/fire_smoke_cnn.keras, models/labels.txt
        │  convert_to_tflite.py
        ▼
models/fire_smoke_cnn_int8.tflite
        │  evaluate.py (sanity check accuracy after quantization)
        │  export_c_array.py
        ▼
../fire_detection_esp/main/model_data.{hpp,cpp}
```

## Setup

```bash
make venv
source .venv/bin/activate
```

## 1. Get data

Populate `data/raw/<class>/*.jpg`, one folder per class, e.g.:

```
data/raw/fire/*.jpg
data/raw/smoke/*.jpg
data/raw/none/*.jpg
```

Folder names become the model's class labels (sorted alphabetically). You
need at least two classes, and "none" (negative/background images) matters
as much as the positive classes for a usable detector.

To get started quickly:

```bash
make download   # pulls a starter fire/non-fire dataset via kagglehub (see
                # download_dataset.py for details and caveats -- you'll need
                # a Kaggle account/API token, and it does NOT include smoke).
```

Add `data/raw/smoke/*.jpg` yourself (e.g. crop frames from a fire+smoke
object-detection dataset, or search Kaggle for a smoke-classification set)
if you want smoke as its own class rather than merging it into "fire".

## 2. Run the pipeline

```bash
make prepare   # splits data/raw into train/val/test (70/15/15)
make train     # trains the CNN, ~a few minutes on CPU for a small dataset
make convert   # int8-quantizes to .tflite
make evaluate  # accuracy/confusion matrix on the test set, post-quantization
make export    # writes model_data.hpp/.cpp into ../fire_detection_esp/main/
```

or all at once (skipping download, assuming `data/raw/` is already populated):

```bash
make pipeline
```

## Model

`model.py` builds a small depthwise-separable CNN (same architectural
family as MobileNet / the TFLite Micro "person detection" reference model):
96x96x3 input, ~5 depthwise-separable blocks, global average pooling, dense
softmax head. This is deliberately small -- the ESP32 needs to fit the
whole interpreter, tensor arena, and activations in a few hundred KB of RAM,
not just the model weights. If you need more accuracy and have headroom
(e.g. an S3 board with PSRAM), widen the `filters` in `model.py` and/or
increase `IMAGE_SIZE` in `config.py`; both directly trade off against the
tensor arena size configured in `fire_detection_esp/main/inference.cpp`.

## Why int8 quantization

TensorFlow Lite Micro on ESP32 needs a fully integer-quantized model (int8
weights, activations, input and output) -- there's no practical float32
inference path at any useful framerate without an FPU-heavy CPU. This
happens in `convert_to_tflite.py` via post-training quantization, using a
sample of the training set as the representative dataset TFLite needs to
compute per-tensor quantization ranges. `evaluate.py` re-checks accuracy
after quantization since int8 rounding can occasionally hurt a borderline
class more than others.

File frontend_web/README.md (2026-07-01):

# frontend_web

Operator web UI for the [Auto Flight](../README.md) project's ground station. It's a Vue 3 + TypeScript single-page app that walks an operator through connecting to the [base_station](../base_station), planning a coverage area, reviewing the generated route, and monitoring the flight — talking to the base station's REST/WebSocket API described in [base_station/components/frontend](../base_station/components/frontend/README.md).

In production this app isn't hosted anywhere separate: it's built to static files and flashed into the base station's LittleFS partition, which the firmware then serves itself (see [Building & preparing for flashing](#building--preparing-for-flashing) below).

## What it does

- **Mission wizard**: a step-by-step flow (`src/stores/store.ts`'s `ConfigurationState`) that gates progress through `Connection → Area Selection → Route Approval → Starting → Flying → Finishing`. The current step is shown in the always-visible [StepView](src/components/StepView.vue) sidebar.
- **Connection overview** ([ConnectionOverview.vue](src/views/ConnectionOverview.vue)): live status of the base station and plane links, plus their sub-links (GPS, barometer, motor control, magnetometer), polled from `GET /api/status`. The wizard only allows moving on once everything reports connected.
- **Area planner** ([AreaPlanner.vue](src/views/AreaPlanner.vue) + [PolygonMap.vue](src/components/PolygonMap.vue)): draw a coverage polygon on a Leaflet map (via `leaflet-draw`) over the live base station/plane positions, then submit it with `POST /api/area`.
- **Route preview** ([RoutePreviewView.vue](src/views/RoutePreviewView.vue) + [RouteMap.vue](src/components/RouteMap.vue)): polls `GET /api/route` until the base station has computed a coverage route from the submitted polygon, then renders it alongside the flown flight history.
- **Live telemetry**: a WebSocket connection (`GET /api/ws`, wired up in `src/stores/store.ts` / `src/stores/websocketMessage.ts`) receives pushed `flight`, `connection` and `sensor` packets every 5 seconds and keeps the Pinia-less reactive store (`src/stores/store.ts`) up to date across the whole app — base/plane position, flown route, planned route, connection states and barometric pressure/altitude.
- **Connection status button** ([ConnectionStatusButton.vue](src/components/ConnectionStatusButton.vue)): persistent header control showing base/plane link state at a glance.

The WebSocket/REST packet shapes consumed here mirror the backend's `FrontendPackets.hpp` — a copy is kept at [references/FrontendPackets.hpp](references/FrontendPackets.hpp) for reference; the TypeScript equivalents live under [src/types](src/types) and [src/stores/websocketMessageParser.ts](src/stores/websocketMessageParser.ts).

## Tech stack

- [Vue 3](https://vuejs.org/) (`<script setup>`, Composition API) + [Vite](https://vite.dev/) + TypeScript
- [Vue Router](https://router.vuejs.org/) for the view/wizard navigation ([src/router/index.ts](src/router/index.ts))
- [Leaflet](https://leafletjs.com/) / [@vue-leaflet/vue-leaflet](https://github.com/vue-leaflet/vue-leaflet) + [leaflet-draw](https://github.com/Leaflet/Leaflet.draw) for the map and polygon drawing
- [@vueuse/core](https://vueuse.org/) for the WebSocket client and responsive-layout helpers
- [Playwright](https://playwright.dev/) for end-to-end tests, [ESLint](https://eslint.org/) + [oxlint](https://oxc.rs/docs/guide/usage/linter) for linting, [Prettier](https://prettier.io/) for formatting

## Prerequisites

- [Node.js](https://nodejs.org/) `^20.19.0` or `>=22.12.0`, and npm (see `engines` in [package.json](package.json))
- A base station reachable on the network — either the real [base_station](../base_station) firmware, or `WIFI_DEV_MODE` pointing it at your dev WiFi (see the [base_station README](../base_station/README.md#configuration))

## Project setup

```sh
npm install
```

### Compile and hot-reload for development

```sh
npm run dev
```

By default, Vite proxies `/api` (REST) and `/api/ws` (WebSocket) to a hardcoded base station IP in [vite.config.ts](vite.config.ts) (`server.proxy`). Change that IP to match your base station's address on the network before running `npm run dev` — otherwise the app loads but every API call/WebSocket connection will fail.

## Testing

### Type-checking and linting

```sh
npm run type-check   # vue-tsc --build
npm run lint         # oxlint --fix, then eslint --fix
```

### End-to-end tests (Playwright)

```sh
# Install browsers for the first run
npx playwright install

# When testing on CI, must build the project first
npm run build

# Runs the end-to-end tests
npm run test:e2e
# Runs the tests only on Chromium
npm run test:e2e -- --project=chromium
# Runs the tests of a specific file
npm run test:e2e -- tests/example.spec.ts
# Runs the tests in debug mode
npm run test:e2e -- --debug
```

`playwright.config.ts` starts `npm run preview` against the built `dist/` output, so the e2e suite exercises the same static files that get flashed to the base station, not the dev server.

## Building & preparing for flashing

The base station firmware serves this app's build output directly from flash — there is no separate web server to deploy to. To produce the files the firmware expects:

```sh
npm run build   # type-checks, then builds to dist/
```

This runs `vue-tsc --build` followed by `vite build`, outputting static files to `frontend_web/dist`. [`base_station/static`](../base_station/static) is a symlink to `../frontend_web/dist`, and the base station's [CMakeLists.txt](../base_station/CMakeLists.txt) packages that `static` directory into a LittleFS image for the `storage` partition (`littlefs_create_partition_image(storage static FLASH_IN_PROJECT)`), which `idf.py flash` writes to the device alongside the firmware image.

So, to get a UI change onto real hardware:

1. `npm run build` here — the resulting `dist/` is picked up automatically via the `static` symlink.
2. `cd ../base_station && idf.py build` — bundles `static/` (i.e. this app's `dist/`) into the `storage` LittleFS partition.
3. `idf.py -p <PORT> flash monitor` — flashes both the firmware and the partition image.

See the [base_station README](../base_station/README.md#building--running) for the full firmware build/flash walkthrough. For iterating on the UI itself, prefer `npm run dev` against a running base station (see above) — no rebuild/reflash needed for frontend-only changes.

## Project layout

| Path | What it is |
|---|---|
| [src/views](src/views) | Top-level wizard steps/pages routed via [src/router](src/router): connection overview, area planner, route preview, map. |
| [src/components](src/components) | Shared UI: step sidebar, connection status button, the two Leaflet map wrappers (`PolygonMap`, `RouteMap`). |
| [src/stores](src/stores) | Reactive app state (`store.ts`), WebSocket message handling and packet parsing/normalization. |
| [src/types](src/types) | TypeScript types for the connection/flight/sensor/coordinate packets, mirroring the backend's `FrontendPackets.hpp`. |
| [src/api](src/api) | Small REST fetch helpers (e.g. `status.ts`). |
| [src/composables](src/composables) | Reusable composition-API logic (e.g. `useConnectionItems`). |
| [references/FrontendPackets.hpp](references/FrontendPackets.hpp) | Copy of the backend packet definitions, kept for reference when updating the TS types. |
| [e2e](e2e) | Playwright end-to-end tests, run against the built `dist/` output. |

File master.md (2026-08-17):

Teilaufgaben
- Flug fertigstellen, vollkommen autonomes Fliegen
  - I2C fixen
  - Steuerung testen und optimieren
- optimieren des Setups/Konfiguration
  - evtl. auch Schwarmkonfiguration
  - Konfigurationsmöglichkeiten anbieten für
    - Kamera (FOV, Modell, Algorithmus?)
    - Schwadbreite, Überlappungsfaktor
    - Akkukapazität
    - Flugzeug, -größe, -gewicht?
- Pfadalgorithmen durchtesten/evaluieren
  - auch anhand:
    - Flugstrecke
    - theoretischer Flugdauer
    - Akkukapazitäts Schätzung
- Bildabdeckung mittel FOV und Bodendistanz berechenbar
  - Bodendistanz berechenbar über?
    - LiDAR für 40m+?
    - Barometer: Problem bei Bergen etc. -> Höhenkarte
    - GPS: Problem bei Bergen etc. -> Höhenkarte
- umschreiben/ergänzen der Kommunikation Basis <-> Gerät durch Bluetooth und App um besser Offline mit Karten arbeiten zu können
- Bildverarbeitung: Feuer-/Raucherkennung
  - Möglichkeiten:
    - naiver Algorithmus (grau bzw. rotanteil im Bild, evtl. mit Wärmebild Kamera)
    - mini CNN auf separatem ESP (Inspo: https://github.com/DaveBben/esp32-llm)

Anmeldungsrelevant:
- Prüfer
  - Matteo Zella
  - Peter Davids
- Titel Ideen
  - Wahrnehmungsbasierte und dynamikgerechte Flächenabdeckung mit einem Starrflügel-UAV
- Titel Ideen der KI
  - Entwurf und Umsetzung eines autonomen Starrflügel-UAV-Systems für flächendeckende Überwachungsflüge
  - Ein ressourcenbeschränktes Avioniksystem für autonome Flächenabdeckungsflüge mit Starrflügel-UAVs
  - Sicherheitskritische Architektur für ein autonomes Segelflugzeug mit manueller Übersteuerungsebene
  - Evaluation von Coverage-Path-Planning-Algorithmen für energiebeschränkte Starrflügel-UAVs
  - Von der Fläche zur Flugroute: Streifenmuster-Routenplanung unter Berücksichtigung von Akku- und Kameraparametern
  - Ein ressourcenschonendes LoRa-Kommunikationsprotokoll für die Telemetrie autonomer Kleinfluggeräte
  - Entkoppelte Funk- und Weboberflächen-Architektur zur Fernüberwachung autonomer UAV-Missionen
  - Sensorfusion und PID-basierte Lage-/Kursregelung für ein GPS-, IMU- und magnetometergestütztes Starrflügel-UAV
  - Eingebettete Branderkennung mittels CNN auf ressourcenbeschränkter ESP32-Hardware für UAV-gestützte Flächenüberwachung
  - Von der Bildaufnahme zur Kanteninferenz: ein TinyML-Ansatz zur Feuer-/Raucherkennung auf Mikrocontrollern für UAV-Einsätze
  - Autonomie mit Rückfallebene: Entwurf eines fail-safe-fähigen UAV-Systems für kartografische Flächenabdeckung
  - Evaluation bildbasierter Branderkennungsalgorithmen für den Einsatz auf ressourcenbeschränkter UAV-Hardware
  - Naiver Bildverarbeitungsansatz vs. eingebettetes CNN: ein Vergleich zur Feuer-/Raucherkennung auf Mikrocontroller-Ebene
  - Von der Heuristik zum TinyML-Modell: Evaluation von Algorithmen zur Branderkennung für autonome Flächenüberwachung
  - Evaluation von Pfadplanungsalgorithmen für die kamerabasierte Flächenabdeckung mit einem Starrflügel-UAV
  - Flugstrecke, Flugdauer, Bildabdeckung: eine vergleichende Evaluation von Coverage-Path-Algorithmen unter Energie- und Sensorrestriktionen
  - Algorithmenevaluation für autonome UAV-Flächenüberwachung: Coverage-Path-Planning und eingebettete Branderkennung
  - Von der Routenplanung zur Detektion: vergleichende Evaluation von Pfad- und Bildverarbeitungsalgorithmen für ein autonomes Überwachungs-UAV
  - Algorithmische Grundlagen eines autonomen Flächenüberwachungs-UAV: Pfadplanung, Bildabdeckungsberechnung und eingebettete Branderkennung im Vergleich
  - Wahrnehmungsbasierte und ressourcenbeschränkte Branderkennung mit einem Starrflügel-UAV
  - Vergleichende und eingebettete Branderkennung mittels Bildverarbeitung mit einem Starrflügel-UAV
  - Algorithmenbasierte und ressourcenschonende Feuer-/Raucherkennung mit einem autonomen Starrflügel-UAV
  - Bildbasierte und echtzeitfähige Branderkennung für die Flächenüberwachung mit einem Starrflügel-UAV
  - Vergleichende und dynamikgerechte Pfad- und Detektionsalgorithmen für ein autonomes Starrflügel-UAV
  - Wahrnehmungsbasierte und mikrocontrollertaugliche Algorithmenevaluation zur Branderkennung mit einem Starrflügel-UAV
  - Algorithmische und ressourcenbewusste Flächenabdeckung und Branderkennung mit einem Starrflügel-UAV
  - Luftgestützte Waldbrandfrüherkennung: Entwicklung und Evaluation eingebetteter Bildverarbeitungsalgorithmen für ein autonomes UAV
  - Vom Rauch zum Alarm: bildbasierte Branderkennung auf einem autonomen Starrflügel-UAV
  - Frühwarnung aus der Luft: ein Algorithmenvergleich zur automatisierten Branderkennung mit einem autonomen Kleinflugzeug
  - Brandwache ohne Pilot: Konzeption und Evaluation eines UAV-gestützten Früherkennungssystems für Wald- und Feldbrände
  - Auto Flight: Evaluation eingebetteter Branderkennungsalgorithmen auf einem autonomen Starrflügel-UAV
  - Augen über dem Feld: Bildverarbeitungsalgorithmen zur Branderkennung auf einem autonomen UAV im Vergleich
  - Klein, autonom, wachsam: eingebettete Branderkennung auf einem ressourcenbeschränkten Starrflügel-UAV
  - Reicht ein einfacher Algorithmus? Klassische Bildverarbeitung vs. eingebettetes CNN zur Branderkennung
  - Klassisch oder gelernt? Evaluation von Bildverarbeitungsansätzen zur Branderkennung für autonome UAVs
  - Wie viel Intelligenz passt auf einen Mikrocontroller? Branderkennung zwischen Heuristik und neuronalem Netz
  - Genauigkeit vs. Ressourcenverbrauch: eine systematische Evaluation von Branderkennungsalgorithmen auf Embedded-Hardware
  - Erkennungsgüte unter Realbedingungen: Evaluation von Bildverarbeitungsalgorithmen zur Branderkennung im UAV-Einsatz
  - Kostengünstige Branderkennung: ein Vergleich klassischer Bildverarbeitung und eingebetteter neuronaler Netze auf Mikrocontrollern
  - Edge AI im Sinkflug: Evaluation eingebetteter neuronaler Netze zur Branderkennung auf einem autonomen UAV
  - TinyML in der Luft: Entwicklung und Bewertung eines CNN-basierten Branderkennungssystems für Mikrocontroller
  - Neuronale Netze am Limit: Branderkennung mit TinyML auf einem autonomen Kleinflugzeug

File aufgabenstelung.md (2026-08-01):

1. *Technische Dokumentation (ca. 6–8 Seiten, PDF)*
    Die Dokumentation soll das entwickelte System nachvollziehbar und technisch fundiert beschreiben. Erwartet werden insbesondere:

    - Zielsetzung und Anwendungsszenario
    - Anforderungen und Randbedingungen
    - Systemarchitektur (Hardware und Software)
    - technische Umsetzung und wesentliche Designentscheidungen
    - Tests und Evaluation
    - bekannte Einschränkungen und mögliche Verbesserungen
    - bei Gruppenarbeiten: kurze Darstellung der individuellen Beiträge

    Die Dokumentation soll dabei keine chronologische Beschreibung der durchgeführten Arbeiten sein, sondern das entwickelte System erklären, technische Entscheidungen begründen und die erzielten Ergebnisse kritisch bewerten.

    Bitte geben Sie am Ende der Dokumentation außerdem kurz an,
    ob und in welchem Umfang ich die Ergebnisse bzw. das entwickelte Projekt für weitere Lehr-, Forschungs- oder Demonstrationszwecke nutzen darf,
    und ob das eingereichte Video für die Darstellung und Bewerbung meiner Lehraktivitäten verwendet werden darf.

    Eine Zustimmung zur weiteren Nutzung ist selbstverständlich freiwillig.

2. *Projektvideo (max. 1 Minute)*
    Das Video soll einen kompakten Einblick in Ihr Projekt geben und insbesondere die entwickelte Lösung in Aktion zeigen. Ziel ist es, innerhalb einer Minute die Aufgabenstellung, die technische Lösung und das wichtigste Ergebnis verständlich zu vermitteln.

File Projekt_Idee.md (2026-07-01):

# Initiale Idea

## Grundidee
Ein autonomes Segelflugzeug, welches vordefinierte Flächen, beispielsweise Felder, abfliegt und Fotografiert. Über die Bilder können dann beispielsweise Ernteerträge geschätzt, Unkraut erkannt oder anderweitiger Handlungsbedarf erkannt werden. Das Flugzeug soll dabei im Notfall über eine Fernsteuerung manuell gesteuert werden können.

## Kommunikation, Konfiguration und Navigation
Das Flugzeug kommuniziert über LoRa mit einer Basisstation, welche über einen Hotspot, eine Webseite bereitstellt, die die Konfiguration der Flugfläche und weiterer Daten ermöglicht. 

Mittels Beschleunigungssensor, Barometer und Magnetometer soll die Höhe und Lage des Flugzeugs bestimmt werden können. Über GPS kann die korrekte Position ermöglicht werden und soll so das automatische Abfliegen der berechneten Waypoints gewährleisten.

## Mögliche Verwendung
Mit der Erweiterung des Systems durch eine Kamera, können Luftbilder aufgenommen werden, die dann für die Analyse von landwirtschaftlichen Flächen verwendet werden können.

Die Kommunikation über LoRa ermöglicht eine große Reichweite, jedoch eine geringe Bandbreite. Daher ist es notwendig, die Datenmenge, die über LoRa übertragen wird, zu minimieren. Die Bilder können daher auf einer SD-Karte gespeichert werden und nur die relevanten Daten, wie GPS-Koordinaten und Statusinformationen, werden über LoRa übertragen. Alternativ zur Speicherung auf einer SD-Karte, die manuell ausgelesen werden müsste, könnte das Flugzeug bei der Landung die Bilder über WLAN an die Basisstation übertragen. Dies würde eine schnellere und einfachere Auswertung der Bilder ermöglichen, da sie direkt auf dem Computer der Basisstation verfügbar wären.

## Start und Landung
Für den Start soll das Flugzeug von Hand geworfen werden können und sofort mit der automatischen Navigation beginnen. Für die Landung soll das Flugzeug zum Startpunkt zurückkehren und entweder manuell gelandet, gefangen oder mittels eines genauen Laser Entfernungsmessers versuchen vorsichtig auf einer Wiese zu landen.

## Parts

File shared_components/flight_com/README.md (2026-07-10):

# flight_com

ESP-IDF component that defines the application-level protocol spoken between the plane (`flight_controller`) and the ground `base_station`. It builds on top of [`lora_com`](../lora_com) (which handles the physical radio link, fragmentation, ACKs/retries) and adds a small set of typed, serializable packets plus the logic to build, send and decode them.

Both sides of the link include this same component; which packets a device is allowed to *send* is controlled at compile time by `FLIGHT_DEVICE_TYPE_PLANE` / `FLIGHT_DEVICE_TYPE_BASE_STATION`, but either side can *decode* any packet type.

## What it does

- Defines a fixed set of packet structs (`packets/*.hpp`), each carrying a `timestamp` and a `PacketType` tag plus its own payload.
- Serializes packets to a flat `uint8_t` buffer (`serialize()`) and hands them to `LoRa_Communication.sendData()`.
- Decodes a raw buffer or `LoRaPacket` back into the right packet struct (`Flight_Communication::decodePacket()`), based on the `PacketType` in the header, with size validation per type.
- Provides `Flight_Communication::send*()` helpers that pull live data from other components (`GPS_Reader`, `Barometer`, `FlightStorage`, `MotorComMaster`) and send the corresponding packet.
- Gates plane-only senders (`sendPlannedRoute`, `sendRouteHistory`, `sendComponentStatus`) and base-station-only senders (`requestRouteHistory`, `sendPlannedArea`) behind `#ifdef FLIGHT_DEVICE_TYPE_PLANE` / `FLIGHT_DEVICE_TYPE_BASE_STATION`.

## Packets

Every packet starts with a `BasePacket` header (`packets/base.hpp`): a `time_t timestamp` and a `PacketType type` byte. Variable-length packets additionally encode a `size_t length` right after the header, followed by that many `Coordinate` elements.

| Packet | Type | Sent by | Direction | Payload |
|---|---|---|---|---|
| `BasePacket` (as `ROUTE_HISTORY_REQUEST`) | `0x33` | base station | base → plane | header only — asks the plane to send its full route history |
| `SensorUpdate` | `0x10` | both | plane ↔ base | `pressure` (hPa, from `Barometer`), `heading` (degrees `[0, 360)`, rounded, from `Magnetometer`, plane only) |
| `PositionUpdate` | `0x11` | both | plane ↔ base | current `Coordinate` (from `GPS_Reader`) |
| `ComponentStatus` | `0x12` | plane | plane → base | `ConnectionState` of `gps`, `barometer`, `motorControl`, `magnetometer`, `accelerometer` |
| `PlannedRoutePacket` | `0x30` | plane | plane → base | `route`: ordered list of `Coordinate` waypoints the plane computed to cover the planned area |
| `PlannedAreaPacket` | `0x31` | base station | base → plane | `shape`: list of `Coordinate` describing the area the plane should cover |
| `FlightHistoryPacket` | `0x32` | plane | plane → base | `history`: list of `Coordinate` the plane has actually flown since takeoff |

`SensorUpdate`, `PositionUpdate` and `ComponentStatus` are fixed-size and sent periodically by both sides (see `sendUpdateTask()` in the respective controllers). The route/area/history packets are variable-length and event-driven — e.g. `PlannedAreaPacket` is sent whenever the operator edits the area in the base station's web UI, and `PlannedRoutePacket`/`FlightHistoryPacket` are sent by the plane in response.

## Usage

Sending:

```cpp
#include "Flight_Communication.hpp"

Flight_Communication::sendPosition();      // reads GPS_Reader, sends PositionUpdate
Flight_Communication::sendSensorUpdate();  // reads Barometer, sends SensorUpdate

#ifdef FLIGHT_DEVICE_TYPE_BASE_STATION
Flight_Communication::sendPlannedArea(shape); // std::vector<Coordinate>
#endif
```

Receiving — register a callback with `LoRa_Communication` and decode incoming payloads:

```cpp
LoRa_Communication.registerReceivePacketCallback([](const LoRaPacket& packet) {
    auto decoded = Flight_Communication::decodePacket(packet);
    if (!decoded) return; // too short / unknown type / malformed — already logged

    switch (decoded->type) {
    case PacketType::POSITION: {
        auto* pos = reinterpret_cast<PositionUpdate*>(decoded.get());
        FlightStorage.updatePlanePosition(pos->position, pos->timestamp);
        break;
    }
    // ... one case per PacketType you care about
    }
});
```

`decodePacket()` returns a `std::unique_ptr<BasePacket>` (or `nullptr` for an invalid/too-short/unknown packet). The concrete type is known from `decoded->type`, so callers `reinterpret_cast` it to the matching struct (`SensorUpdate`, `PositionUpdate`, `ComponentStatus`, `PlannedRoutePacket`, `PlannedAreaPacket`, `FlightHistoryPacket`) before reading its extra fields. This is how both `FlightController.cpp` and `BaseController.cpp` consume decoded packets — the switch feeds each field straight into `FlightStorage` (e.g. `updatePlanePosition`, `updatePlannedArea`, `updatePlaneBarometerConnectionState`), which is the shared state that drives route planning, the web UI and connection-status display on both ends.

## Dependencies

- [`lora_com`](../lora_com) — the actual radio transport (`LoRa_Communication`, `LoRaPacket`).
- [`flight_data`](../flight_data) — `Coordinate`/`ConnectionState` types and `FlightStorage` (consumed by callers of `decodePacket`, not by this component directly).
- `gps`, `barometer` — read by the `send*()` helpers to fill packet payloads.
- `motor_com_master` (plane build only) — optional dependency, included when `FLIGHT_DEVICE_TYPE_PLANE` is set.
- `nlohmann-json` — private dependency (see [CMakeLists.txt](CMakeLists.txt)).
- ESP-IDF: `driver`, `freertos`, `esp_timer`.

## Files

| File | Contents |
|---|---|
| [Flight_Communication.hpp](Flight_Communication.hpp) / [.cpp](Flight_Communication.cpp) | Public API: `begin()`, `send*()` helpers, `decodePacket()`. |
| [Packets.hpp](Packets.hpp) | Umbrella header pulling in all packet definitions. |
| [packets/base.hpp](packets/base.hpp) | `PacketType` enum, `BasePacket` header struct. |
| [packets/sensor.hpp](packets/sensor.hpp) | `SensorUpdate`. |
| [packets/position.hpp](packets/position.hpp) | `PositionUpdate`. |
| [packets/component.hpp](packets/component.hpp) | `ComponentStatus`. |
| [packets/route.hpp](packets/route.hpp) | `PlannedRoutePacket`. |
| [packets/area.hpp](packets/area.hpp) | `PlannedAreaPacket`. |
| [packets/history.hpp](packets/history.hpp) | `FlightHistoryPacket`. |

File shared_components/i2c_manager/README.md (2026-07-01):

# I2C Manager

A small singleton wrapper around ESP-IDF's I2C bus that provides a single, shared `i2c_bus_handle_t` to all components on the flight controller / base station that need to talk to I2C devices (e.g. magnetometer, IMU).

## What it does

- Lazily initializes a single I2C master bus (`I2C_NUM_0`) on first use via `I2CManager::getBus()`.
- Configures SDA/SCL pins and pull-ups, and sets the bus clock to 400 kHz.
- Waits for devices to finish power-on reset before creating the bus, then resets the underlying master bus handle.
- Scans the bus for connected devices and logs how many were found.
- Hands back the same bus handle on every subsequent call, so callers don't need to manage initialization order or ownership themselves.

## Usage

```cpp
#include "i2c_manager.hpp"

i2c_bus_handle_t bus = I2CManager::getBus();
```

## Configuration

Pin assignments are configurable via `idf.py menuconfig` under **I2C Manager Settings**:

- `CONFIG_I2C_PIN_SDA` – GPIO pin for I2C SDA (default: 47)
- `CONFIG_I2C_PIN_SCL` – GPIO pin for I2C SCL (default: 48)

## Dependencies

- ESP-IDF (`>=4.1.0`)
- `esp_driver_i2c` (ESP-IDF component)
- `esp_driver_gpio` (ESP-IDF component, private)
- `freertos` (ESP-IDF component, private)
- [`espressif/i2c_bus`](https://components.espressif.com/components/espressif/i2c_bus) `^1.5.1`

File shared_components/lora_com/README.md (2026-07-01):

# lora_com

ESP-IDF component providing the long-range radio link between the plane (`flight_controller`) and the ground `base_station`. It wraps an SX1262 LoRa module (via [RadioLib](https://github.com/jgromes/RadioLib)) with a small custom protocol on top: message fragmentation/reassembly, acknowledgements with retries, keep-alive pings and connection-state tracking. Consumers just call `sendData()` and register a callback for incoming payloads — the wire protocol is entirely hidden.

Both sides of the link (`flight_controller` and `base_station`) include this same component and must be configured with matching radio parameters to talk to each other.

## Capabilities

- **Singleton API** — `LoRa_Communication` is a global singleton (`LoRa_CommunicationClass::getInstance()`), so there's exactly one radio instance per device.
- **Arbitrary-length send/receive** — `sendData()` transparently splits payloads larger than one LoRa packet (255 bytes minus the internal header) into fragments and reassembles them on the receiving end before your callback ever sees them.
- **Reliable delivery** — every data packet requires an ACK; if none arrives within the timeout, the packet is retransmitted (up to a configurable retry count) before the send is reported as failed.
- **Keep-alive / link status** — a background task sends a `PING` whenever the link has been idle for too long, and updates a shared `ConnectionState` (`CONNECTING` / `CONNECTED`) in `FlightStorage` so the rest of the firmware (and the web UI) can show whether the peer is reachable.
- **Duplicate/echo suppression** — recently-sent packets are tracked so a device doesn't process its own transmission if it happens to hear it echoed back.
- **Signal diagnostics** — `getLastPacketRSSI()` / `getLastPacketSNR()` expose the last packet's signal strength and signal-to-noise ratio.
- **Callback-based receive API** — register any number of `std::function<void(const LoRaPacket&)>` callbacks via `registerReceivePacketCallback()`; they're invoked from a dedicated worker task, not from ISR/receive-task context.
- **Interrupt or poll-driven receive** — if `CONFIG_LORA_DIO0_PIN` is wired up, the receive task blocks on the DIO0 IRQ; otherwise it falls back to polling the radio.
- **AES-128-GCM primitives included** — `lora_encryption.cpp` implements authenticated encrypt/decrypt of payloads, but it is **not currently wired into `sendData()`/the receive path** (no key is ever set) — packets go over the air in plaintext today. Treat this as a building block for future work, not an active feature.

## Usage

```cpp
#include "LoRa_Communication.hpp"

void init() {
    LoRa_Communication.begin(); // starts the radio + background tasks (receive, ping, callback worker, fragment joiner)

    LoRa_Communication.registerReceivePacketCallback([](const LoRaPacket& packet) {
        // packet.payload / packet.length — already reassembled, ACKed, and de-duplicated
        handleIncoming(packet.payload, packet.length);
    });
}

void sendTelemetry(const uint8_t* data, size_t size) {
    LoRa_Communication.sendData(data, size); // fragments, sends, waits for ACK(s), retries on loss
}
```

`begin()` must be called once at startup before sending/receiving. It creates the SPI/GPIO-backed radio, configures it from Kconfig values, and spins up four FreeRTOS tasks:

| Task | Purpose |
|---|---|
| `lora_rx_task` | Waits for incoming packets (DIO0 IRQ or poll), parses headers, handles ACK/PING packets, hands data packets/fragments off to the fragment cache. |
| `lora_ping_task` | Sends a `PING` when the link has been idle longer than `CONFIG_LORA_PING_INTERVAL`; also expires old sent-packet history. |
| `lora_callback_worker` | Drains fully-received packets and invokes the registered callbacks outside of the receive task. |
| `lora_join_fragments` | Reassembles multi-fragment messages once all fragments for a `messageId` have arrived. |

## Wire protocol (internal)

Every over-the-air packet starts with an internal header (`LoRa_Packet_Internal`): a `PacketType` (`HEADER`/`ACK`/`PING`), a `messageId`, and fragmentation info (`fragmentId`/`totalFragments`/`payloadLength`). `sendData()` assigns a new `messageId` per call, splits the payload into as many `HEADER`-type fragments as needed (max ~255 bytes minus the header per fragment), and requires an ACK per fragment before considering the fragment sent.

This is example/thesis-project-scale plumbing, not a general-purpose radio stack — there's no addressing/routing (it's a point-to-point link between exactly two devices) and no encryption in the current send/receive path (see above).

## Configuration

All radio and link parameters are exposed via `idf.py menuconfig` → *LoRa Communication Settings* (backed by [Kconfig](Kconfig)):

| Setting | Default | Notes |
|---|---|---|
| `LORA_FREQUENCY` | 868 MHz | ISM band; must match on both ends. |
| `LORA_TX_POWER` | 17 dBm | 2–17; higher = more range/power draw. |
| `LORA_SPREADING_FACTOR` | 7 | 6–12; higher = more range, lower throughput. Must match on both ends. |
| `LORA_BANDWIDTH` | 125 kHz | Must match on both ends. |
| `LORA_CODING_RATE_DENOMINATOR` | 6 | 4/X error correction; higher = more robust, slower. |
| `LORA_PREAMBLE_LENGTH` | 8 symbols | |
| `LORA_PING_INTERVAL` | 30 s | Send a keep-alive PING if idle this long. |
| `LORA_SYNC_WORD` | 0x34 | Must match on both ends; keep off the public LoRaWAN sync word (`0x12`) for a private link. |
| `LORA_DIO0_PIN` | 14 | IRQ pin; enables interrupt-driven receive instead of polling. |
| `LORA_CS_GPIO` / `LORA_RST_GPIO` / `LORA_MISO_GPIO` / `LORA_MOSI_GPIO` / `LORA_SCK_GPIO` / `LORA_BUSY_GPIO` | 8 / 12 / 11 / 10 / 9 / 13 | SX1262 SPI wiring, board-specific (defaults match the Heltec LoRa32 V3). |

`flight_controller` and `base_station` must use matching frequency, spreading factor, bandwidth and sync word to communicate; TX power, ping interval and pin mapping can differ per device.

## Dependencies

- [`jgromes/radiolib`](../jgromes__radiolib) (`^7.6.0`) — SX1262 driver, pulled in via [idf_component.yml](idf_component.yml).
- [`flight_data`](../flight_data) — `ConnectionState` type and `FlightStorage`/`helper.hpp` (`isDevicePlane()` / `isDeviceBaseStation()`) used to report connection state to the right side of the link.
- ESP-IDF: `driver`, `freertos`, `esp_timer`, `mbedtls` (AES-GCM), `esp_driver_gpio`, `pthread` (see [CMakeLists.txt](CMakeLists.txt)).
- [`EspHal.h`](EspHal.h) provides the RadioLib hardware abstraction layer for ESP32/ESP32-S3; other targets aren't supported.

## Files

| File | Contents |
|---|---|
| [LoRa_Communication.hpp](LoRa_Communication.hpp) / [.cpp](LoRa_Communication.cpp) | Public API, `begin()`, `sendData()`, fragmentation/send-with-retry logic, singleton. |
| [LoRa_ReceiveTask.cpp](LoRa_ReceiveTask.cpp) | Receive task loop, packet parsing, ACK/PING handling, own-packet filtering. |
| [LoRa_PingTask.cpp](LoRa_PingTask.cpp) | Keep-alive ping loop and sent-packet history cleanup. |
| [LoRa_JoinFragmentsTask.cpp](LoRa_JoinFragmentsTask.cpp) | Reassembles complete multi-fragment messages. |
| [LoRa_CallbackWorkerTask.cpp](LoRa_CallbackWorkerTask.cpp) | Dispatches fully-received packets to registered callbacks. |
| [lora_encryption.cpp](lora_encryption.cpp) | AES-128-GCM encrypt/decrypt helpers (see caveat above). |
| [EspHal.h](EspHal.h) | RadioLib HAL implementation for ESP32/ESP32-S3 (SPI + GPIO). |
| [mutex_helper.hpp](mutex_helper.hpp) | `WITH_MUTEX(...)` RAII-style scope-lock macros used throughout the task loops. |
| [Kconfig](Kconfig) | Radio and pin configuration exposed via `idf.py menuconfig`. |

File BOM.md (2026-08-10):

# Info

Ich besorge die Komponenten selbst, hier aber dennoch eine Übersicht über die benötigten Teile.

# Komponenten
- Segelflugzeug
- 2 LoRa32 (aka. ESP32 inkl. LoRa Modul)
  - https://www.amazon.de/dp/B0CWGTZS3X
- 1 Arduino Nano (ATmega328P)
  - https://www.amazon.de/dp/B01LWSJBTD
- 1 GPS Modul
  - ATGM336H GPS+BDS Dual Mode Module
  - https://www.amazon.de/dp/B0FKH26344
- Beschleunigungssensor / Lagesensor (Drehung und Neigung)
  - https://www.amazon.de/dp/B07BVXN2GP
- Magnetometer (HMC5883L)
  - https://www.amazon.de/dp/B014THA95U
- Level Shifter (3.3V <-> 5V)
  - https://www.amazon.de/dp/B07DKT9JXT
- Boden Entfernungsmessung (für Landung)
  - Time of Flight TOF200C
  - https://www.amazon.de/dp/B0DK2SB3B6
- Barometer (für höhenmessung)
  - https://www.amazon.de/dp/B0DJXB62MN
- Futaba S-BUS Empfänger
  - https://de.aliexpress.com/item/1005007253167246.html
- Futaba Fernsteuerung (min. 5 Kanäle)
  - in meinem Fall Futaba T10CG
- Akkus
-

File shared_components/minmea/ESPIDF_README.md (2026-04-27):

# Original Source code from https://github.com/kosma/minmea/

The original source code comes from this repository: https://github.com/kosma/minmea/tree/master

Only the necessary files for the minmea component have been copied to this directory. The original license is MIT, and it is included in the LICENSE file in this directory.

The code has been adjusted to work for the ESP IDF as a component. In addition inline documentation has been added.

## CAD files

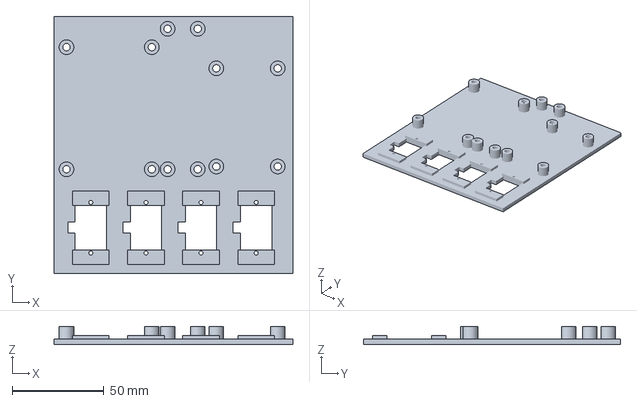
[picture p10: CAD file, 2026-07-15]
3d_models/plane_mount_plate.3mf
130.0 x 140.0 x 9.90 mm

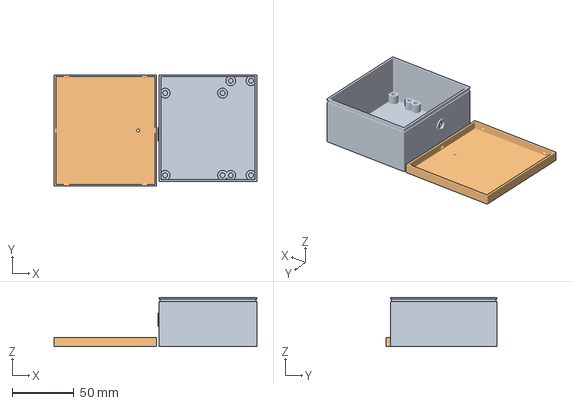
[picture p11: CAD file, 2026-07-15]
3d_models/base_station_case_base.3mf
164.0 x 90.0 x 39.9 mm
case_base.stl
case_lid.stl

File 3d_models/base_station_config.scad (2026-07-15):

// ===================================================================
// Base station case - tunable dimensions.
// Edit values here; case.scad only reads these parameters.
// ===================================================================

// ---- Main PCB (Heltec LoRa32 V3 + GPS module) ----
pcb_main_w = 50;   // X
pcb_main_l = 70;   // Y
pcb_main_h = 26;   // Z, tallest component on the board

// ---- Daughter board (barometer), connected to main PCB by a flying cable ----
pcb_daughter_w = 20;  // X
pcb_daughter_l = 80;  // Y
pcb_daughter_h = 26;  // Z

// ---- Shell thickness ----
wall_thickness  = 1.5;
floor_thickness = 2;
lid_thickness   = 1.5;

// ---- Internal clearances ----
board_clearance_xy = 1.5;  // air gap between a board's edge and the inner wall
board_gap           = 3;   // gap between main PCB and daughter board
top_clearance        = 5;   // clearance above components before the lid underside

// ---- PCB standoffs (self-tapping screw bosses) ----
standoff_enable  = true;
standoff_height  = 6.9;
standoff_od      = 8;
standoff_hole_d  = 4;   // pilot hole for an M2.5 self-tap screw
standoff_inset   = 1.8;     // distance of standoff center from each board corner

// ---- Derived case interior / exterior footprint ----
case_inner_w = pcb_main_w + board_gap + pcb_daughter_w + 2 * board_clearance_xy;
case_inner_l = max(pcb_main_l, pcb_daughter_l) + 2 * board_clearance_xy;
case_inner_h = max(pcb_main_h, pcb_daughter_h) + standoff_height + top_clearance;

case_outer_w = case_inner_w + 2 * wall_thickness;
case_outer_l = case_inner_l + 2 * wall_thickness;

// Board placement: lower-left corner of each board's footprint, in case coordinates.
// Main PCB sits against the x=0 wall (where the LoRa antenna exits); daughter board
// sits alongside it towards +x.
main_origin_x     = wall_thickness + board_clearance_xy;
main_origin_y     = wall_thickness + board_clearance_xy;
daughter_origin_x = main_origin_x + pcb_main_w + board_gap;
daughter_origin_y = wall_thickness + board_clearance_xy;

// ---- LoRa antenna bulkhead mount (SMA-bulkhead style, on the x=0 wall next to the main PCB) ----
lora_thread_d       = 6.2;  // antenna connector thread diameter (given)
lora_hole_clearance = 0.3;  // extra hole diameter over the thread for a clean fit
lora_hole_d         = lora_thread_d + lora_hole_clearance;
lora_boss_od        = 11;   // outer diameter of the printed boss (nut bearing surface)
lora_boss_extra_len = 1;    // boss protrusion beyond the outer wall face (thread purchase for the nut)
lora_mount_y        = main_origin_y + pcb_main_l / 2;                     // centered along the main PCB
lora_mount_z        = floor_thickness + standoff_height + pcb_main_h / 2; // centered on the main PCB height

// ---- Barometer pressure-equalization vent (in the lid, above the daughter board) ----
vent_hole_d = 2.5;
vent_x = daughter_origin_x + pcb_daughter_w / 2;
vent_y = daughter_origin_y + pcb_daughter_l / 2;

// ---- Snap-fit lid retention ----
snap_tab_w              = 4;    // width of each bump
snap_tab_h              = 1.4;  // height of each bump
snap_tab_depth          = 0.8;  // how far the bump reaches into the groove
tab_fit_clearance       = 0.5; // gap so the lid skirt slides over the base
lid_skirt_height        = 6;    // depth of the lid skirt around the base
groove_offset_from_top  = 3;  // distance from the base's top edge down to the groove
snap_tabs_long_side     = 2;    // bumps on each long (Y) skirt wall
snap_tabs_short_side    = 1;    // bumps on each short (X) skirt wall

// ---- Derived lid footprint (skirt sits just outside the base, plus its own wall) ----
lid_offset_x = -tab_fit_clearance - wall_thickness;
lid_offset_y = -tab_fit_clearance - wall_thickness;
lid_inner_w  = case_outer_w + 2 * tab_fit_clearance;
lid_inner_l  = case_outer_l + 2 * tab_fit_clearance;
lid_outer_w  = lid_inner_w + 2 * wall_thickness;
lid_outer_l  = lid_inner_l + 2 * wall_thickness;

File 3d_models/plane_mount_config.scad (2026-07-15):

// ===================================================================
// Plane mounting plate - tunable dimensions.
// This is a MOCKUP to show component layout, not a flight-ready part:
// no fuselage attachment, wiring channels, or weight optimization.
// Edit values here; plane_mount_plate.scad only reads these parameters.
// ===================================================================

// ---- Main PCB (flight controller) ----
pcb_main_w = 50;   // X
pcb_main_l = 70;   // Y
pcb_main_h = 20;   // Z, tallest component on the board (for standoff clearance only)

// ---- Daughter board 1 ----
pcb_d1_w = 20;  // X
pcb_d1_l = 80;  // Y
pcb_d1_h = 20;  // Z

// ---- Daughter board 2 ----
pcb_d2_w = 40;  // X
pcb_d2_l = 60;  // Y
pcb_d2_h = 20;  // Z
pcb_d2_standoff_inset_extra = 1.5;  // this board's holes sit 3mm closer together than the standard grid, on both axes (1.5mm inward per side)

// ---- Plate ----
plate_thickness = 3;
edge_margin     = 5;   // border from outermost feature to plate edge
board_gap       = 5;   // gap between adjacent boards in the row
section_gap     = 10;  // gap between the board row and the servo row

// ---- PCB standoffs (self-tapping screw bosses, same style as the base station case) ----
standoff_enable = true;
standoff_height = 6.9;
standoff_od     = 8;
standoff_hole_d = 4;    // pilot hole for an M2.5 self-tap screw
standoff_inset  = 1.8;  // distance of standoff center from each board corner
pcb_d2_standoff_inset = standoff_inset + pcb_d2_standoff_inset_extra;  // tighter hole spacing for daughter board 2

// ---- Servos ----
// The two mounting holes sit on the tab plane; the servo case hangs
// servo_body_h below that plane. The plate is cut through under each
// servo so the case has room to pass through it (or the servo can just
// stand on top with the case in open air below - either way the plate
// itself must not block that space).
servo_count        = 4;
servo_hole_spacing = 27.5;  // distance between a servo's two mounting holes (front-to-back)
servo_hole_d       = 2.2;   // pilot hole for an M2 self-tap screw
servo_body_w       = 20;    // full footprint, X (across the tabs)
servo_body_l       = 40;    // full footprint, Y (tab-to-tab, along the hole spacing)
servo_body_h       = 17;    // case height below the mounting-hole/tab plane (clearance only, not modeled in Z)
servo_tab_l        = 8;     // length of solid plate left under each tab (must clear the hole, which sits (body_l - hole_spacing)/2 in from the end)
servo_side_margin  = 1.5;   // solid plate rim left on each side of the body cutout, for print strength
servo_cable_w      = 6;     // width (along Y) of the cable-exit notch on the side of the body cutout
servo_cable_ext    = 4;     // how far the cable notch extends past the body cutout, through the side rim
servo_cable_side   = -1;    // which side the cable exits: -1 = -X edge, +1 = +X edge (same for all servos)
servo_row_gap      = 10;    // gap between adjacent servos

// The screws on hand are 2mm longer than the plate is thick, so each of a
// servo's two mounting tabs sits on a small raised pedestal that adds that
// much extra depth, keeping the screw from bottoming out or poking through.
servo_pedestal_enable = true;
servo_pedestal_height = 2;   // matches the screws' 2mm overlength

// ---- Derived servo cutout (the body opening, centered in the footprint) ----
servo_cutout_w = servo_body_w - 2 * servo_side_margin;
servo_cutout_l = servo_body_l - 2 * servo_tab_l;

// ---- Derived board row (main + 2 daughter boards, left to right) ----
board_row_w = pcb_main_w + board_gap + pcb_d1_w + board_gap + pcb_d2_w;
board_row_l = max(pcb_main_l, pcb_d1_l, pcb_d2_l);

// ---- Derived servo row ----
servo_row_w = servo_count * servo_body_w + (servo_count - 1) * servo_row_gap;
servo_row_l = servo_body_l;

// ---- Derived plate footprint ----
plate_w = max(board_row_w, servo_row_w) + 2 * edge_margin;
plate_l = board_row_l + section_gap + servo_row_l + 2 * edge_margin;

// ---- Board placement: lower-left corner of each board's footprint, in plate coordinates ----
// Board row is centered along X, sits above the servo row.
board_row_x0  = (plate_w - board_row_w) / 2;
board_row_y0  = edge_margin + servo_row_l + section_gap;

main_origin_x = board_row_x0;
main_origin_y = board_row_y0;
d1_origin_x   = main_origin_x + pcb_main_w + board_gap;
d1_origin_y   = board_row_y0;
d2_origin_x   = d1_origin_x + pcb_d1_w + board_gap;
d2_origin_y   = board_row_y0;

// ---- Servo placement: lower-left corner of each servo's footprint, in plate coordinates ----
// Servo row is centered along X, sits along the bottom edge.
servo_row_x0 = (plate_w - servo_row_w) / 2;
servo_row_y0 = edge_margin;

function servo_origin_x(i) = servo_row_x0 + i * (servo_body_w + servo_row_gap);
function servo_origin_y(i) = servo_row_y0;

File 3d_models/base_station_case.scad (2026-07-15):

include <base_station_config.scad>
$fn = 48;

// "base"       -> base tray only, print-ready
// "lid"        -> lid only, print-ready (flat face up as modeled; rotate 180 degrees
//                 in your slicer so the skirt points down onto the bed)
// "both"       -> base + lid laid out side by side, for a quick visual check
// "assembled"  -> lid placed on top of the base, for a fit check (not for printing)
part = "both";

if (part == "base") {
    case_base();
} else if (part == "lid") {
    case_lid();
} else if (part == "assembled") {
    case_base();
    translate([0, 0, floor_thickness + case_inner_h])
        case_lid();
} else {
    case_base();
    translate([case_outer_w + 10, 0, 0])
        case_lid();
}

// ===================================================================
// Base tray
// ===================================================================

module case_base() {
    difference() {
        union() {
            case_shell();
            lora_boss();
            if (standoff_enable) standoffs();
        }
        lora_bore();
        snap_groove_ring();
    }
}

module case_shell() {
    outer_h = floor_thickness + case_inner_h;
    difference() {
        cube([case_outer_w, case_outer_l, outer_h]);
        translate([wall_thickness, wall_thickness, floor_thickness])
            cube([case_inner_w, case_inner_l, case_inner_h + 1]);
    }
}

// Continuous groove cut into the outside of the base wall, just below the top edge,
// that the lid's snap bumps click into.
module snap_groove_ring() {
    z0 = floor_thickness + case_inner_h - groove_offset_from_top - tab_fit_clearance;
    groove_h = snap_tab_h + tab_fit_clearance * 1.1;
    translate([0, 0, z0])
    difference() {
        cube([case_outer_w, case_outer_l, groove_h]);
        translate([snap_tab_depth, snap_tab_depth, -0.5])
            cube([case_outer_w - 2 * snap_tab_depth, case_outer_l - 2 * snap_tab_depth, groove_h + 1]);
    }
}

module standoff(x, y) {
    translate([x, y, floor_thickness])
    difference() {
        cylinder(d = standoff_od, h = standoff_height);
        translate([0, 0, -0.5])
            cylinder(d = standoff_hole_d, h = standoff_height + 1);
    }
}

module standoffs() {
    for (p = [
        [main_origin_x + standoff_inset, main_origin_y + standoff_inset],
        [main_origin_x + pcb_main_w - standoff_inset, main_origin_y + standoff_inset],
        [main_origin_x + standoff_inset, main_origin_y + pcb_main_l - standoff_inset],
        [main_origin_x + pcb_main_w - standoff_inset, main_origin_y + pcb_main_l - standoff_inset],
    ]) standoff(p[0], p[1]);

    for (p = [
        [daughter_origin_x + standoff_inset, daughter_origin_y + standoff_inset],
        [daughter_origin_x + pcb_daughter_w - standoff_inset, daughter_origin_y + standoff_inset],
        [daughter_origin_x + standoff_inset, daughter_origin_y + pcb_daughter_l - standoff_inset],
        [daughter_origin_x + pcb_daughter_w - standoff_inset, daughter_origin_y + pcb_daughter_l - standoff_inset],
    ]) standoff(p[0], p[1]);
}

// Boss protrudes outward through the x=0 wall so the LoRa antenna's threaded
// connector can be secured from outside with its nut.
module lora_boss() {
    translate([-lora_boss_extra_len, lora_mount_y, lora_mount_z])
        rotate([0, 90, 0])
            cylinder(d = lora_boss_od, h = lora_boss_extra_len + wall_thickness);
}

module lora_bore() {
    translate([-lora_boss_extra_len - 1, lora_mount_y, lora_mount_z])
        rotate([0, 90, 0])
            cylinder(d = lora_hole_d, h = lora_boss_extra_len + wall_thickness + 2);
}

// ===================================================================
// Lid
// ===================================================================

module case_lid() {
    difference() {
        union() {
            lid_plate();
            lid_skirt();
            snap_bumps();
        }
        translate([vent_x, vent_y, -1])
            cylinder(d = vent_hole_d, h = lid_thickness + 2, $fn = 24);
    }
}

module lid_plate() {
    translate([lid_offset_x, lid_offset_y, 0])
        cube([lid_outer_w, lid_outer_l, lid_thickness]);
}

module lid_skirt() {
    cx0 = -tab_fit_clearance;
    cx1 = case_outer_w + tab_fit_clearance;
    cy0 = -tab_fit_clearance;
    cy1 = case_outer_l + tab_fit_clearance;
    translate([0, 0, -lid_skirt_height])
    difference() {
        translate([lid_offset_x, lid_offset_y, 0])
            cube([lid_outer_w, lid_outer_l, lid_skirt_height + lid_thickness]);
        translate([cx0, cy0, -1])
            cube([cx1 - cx0, cy1 - cy0, lid_skirt_height + lid_thickness + 2]);
    }
}

// A small tapered nub that protrudes in +X from the x=0 plane; instantiated on
// each wall below with the right translate/rotate to point inward.
module snap_bump() {
    d = snap_tab_depth + tab_fit_clearance;
    hull() {
        cube([0.01, snap_tab_w, snap_tab_h], center = true);
        translate([d, 0, 0])
            cube([0.01, snap_tab_w * 0.4, snap_tab_h * 0.4], center = true);
    }
}

function spaced(count, length, margin) =
    [ for (i = [0 : count - 1]) margin + (length - 2 * margin) * (count <= 1 ? 0.5 : i / (count - 1)) ];

module snap_bumps() {
    margin = 8;
    cx0 = -tab_fit_clearance;
    cx1 = case_outer_w + tab_fit_clearance;
    cy0 = -tab_fit_clearance;
    cy1 = case_outer_l + tab_fit_clearance;
    bump_z = -groove_offset_from_top + (snap_tab_h + tab_fit_clearance) / 2;

    for (x = spaced(snap_tabs_long_side, case_outer_w, margin)) {
        translate([x, cy0, bump_z]) rotate([0, 0, 90]) snap_bump();
        translate([x, cy1, bump_z]) rotate([0, 0, -90]) snap_bump();
    }
    for (y = spaced(snap_tabs_short_side, case_outer_l, margin)) {
        translate([cx0, y, bump_z]) snap_bump();
        translate([cx1, y, bump_z]) rotate([0, 0, 180]) snap_bump();
    }
}

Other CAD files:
3d_models/plane_mount_plate.scad

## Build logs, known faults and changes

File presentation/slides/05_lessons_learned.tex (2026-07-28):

\begin{frame}{Erkenntnisse}
  \begin{columns}[T,onlytextwidth]
    \begin{column}{0.5\textwidth}
      \textbf{\faExclamationTriangle\; Herausforderungen}
      \begin{itemize}
        \item Unzureichendes Framework für
              sauberes Komponenten-Management
        \item schlechte/unzureichende LoRa Bibliotheken
        \item Magnetometer blockierte im Dauerbetrieb den gesamten
              I\textsuperscript{2}C-Bus
        \item viele verschiedene Datenquellen und parallele Prozesse
        \item ESP und Arduino beide zerstören beim Booten den I\textsuperscript{2}C Bus
      \end{itemize}
    \end{column}
    \begin{column}{0.5\textwidth}
      \textbf{\faLightbulb\; Lösungen}
      \begin{itemize}
        \item Migration zu ESP-IDF für strukturiertes
              Komponenten- \& Unit-Test-Setup
        \item Eigenes Paketprotokoll mit Fragmentierung für große
              Nutzlasten
        \item Umstellung von Continuous- auf Single-Read-Modus
        \item viele Threads, Queues und Event-Loops für parallele Prozesse und den Datenaustausch
      \end{itemize}
    \end{column}
  \end{columns}
\end{frame}

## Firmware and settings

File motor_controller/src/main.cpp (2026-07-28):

#if true

#include <Arduino.h>
#include "SBUS.h"
#include <Servo.h>
#include <Wire.h>

#define PIN_SERVO1 9
#define PIN_SERVO2 10
#define PIN_SERVO3 11
#define PIN_SERVO4 12

#define I2C_ADDRESS 0x42

#define I2C_RESET_TIMEOUT_MILLIS (1000L)

#define DEBUG_I2C // serial logging if I2C messages arrive
#define DEBUG_PLANE // no need for SBUS channel 5, manual override is always disabled
#define VIRTUAL_DEBUG // output only the servo control signals to serial [-100,100]
//#define DEBUG_SERVO // sweeping from -100 to 100 over all servos

SBUS sbus(Serial);
Servo servo1;
Servo servo2;
Servo servo3;
Servo servo4;

int lastServoValues[4] = {0, 0, 0, 0};

int desiredValueServo1 = 0;
int desiredValueServo2 = 0;
int desiredValueServo3 = 0;
int desiredValueServo4 = 0;

unsigned long lastI2CMessageTime = 0;

// Returns normalized channel value in [-100, 100]
int getChannel(int channel) {
    return (int)sbus.getNormalizedChannel(channel);
}

int clamp(int value, int min, int max) {
    if (value < min) value = min;
    if (value > max) value = max;
    return value;
}

// Maps [-100, 100] to RC PWM range [1000, 2000] µs (center 0 → 1500 µs)
int mapToServo(int value) {
    int clamped = clamp(value, -100, 100);
    return 1500 + clamped * 5;
}

bool isManualOverride() {
#if defined(DEBUG_PLANE) || defined(DEBUG_I2C) || defined(VIRTUAL_DEBUG)
    return false;
#else
    return getChannel(5) > 50;
#endif
}

void I2C_TxHandler() {
    Wire.write(isManualOverride());
}

void I2C_RxHandler(int numBytes) {
#if defined(DEBUG_I2C) && !defined(VIRTUAL_DEBUG)
    Serial.print("I2C_RxHandler called with ");
    Serial.print(numBytes);
    Serial.println(" bytes");
#endif

    char buf[4];
    int bytesRead = Wire.readBytes(buf, 4);
    if (bytesRead != 4) {
        // Handle error: not enough bytes received
        return;
    }
    desiredValueServo1 = (int8_t)buf[0];
    desiredValueServo2 = (int8_t)buf[1];
    desiredValueServo3 = (int8_t)buf[2];
    desiredValueServo4 = (int8_t)buf[3];
#if defined(DEBUG_I2C) || defined(VIRTUAL_DEBUG)
    Serial.print(desiredValueServo1);
    Serial.print(",");
    Serial.print(desiredValueServo2);
    Serial.print(",");
    Serial.print(desiredValueServo3);
    Serial.print(",");
    Serial.println(desiredValueServo4);
#endif
    lastI2CMessageTime = millis();
}

// Hardware I2C pins on the Nano (ATmega328) - not remappable.
#define PIN_I2C_SDA A4
#define PIN_I2C_SCL A5

void setupI2C() {
    // clear internal I2C state machine
    Wire.end();

    // Wire.end() disables the TWI peripheral but doesn't guarantee SDA/SCL
    // come back up cleanly - if the AVR was clock-stretching (holding SCL
    // low) at the moment TWEN got cleared, the pin can stay low afterward.
    // Explicitly release both lines to inputs with pull-ups so we never hand
    // a stuck-low line back to a bus shared with other devices (magnetometer
    // etc.) while TWI is offline.
    pinMode(PIN_I2C_SDA, INPUT_PULLUP);
    pinMode(PIN_I2C_SCL, INPUT_PULLUP);
    delay(10);

    Wire.begin(I2C_ADDRESS);
    Wire.onRequest(I2C_TxHandler);
    Wire.onReceive(I2C_RxHandler);

    lastI2CMessageTime = millis();
}

// value in [-100, 100]
void writeServo(Servo& servo, int value, int id) {
    int pulseWidth = mapToServo(value);
    if (lastServoValues[id - 1] != pulseWidth) {
        servo.writeMicroseconds(pulseWidth);
        lastServoValues[id - 1] = pulseWidth;
    }
}

void setup() {
#if defined(VIRTUAL_DEBUG) || defined(DEBUG_I2C)
    Serial.begin(115200);
#else
    sbus.begin();
#endif

    servo1.attach(PIN_SERVO1);
    servo2.attach(PIN_SERVO2);
    servo3.attach(PIN_SERVO3);
    servo4.attach(PIN_SERVO4);

#ifdef DEBUG_SERVO
    int i = -100;
    while (true) {
        Serial.println("DEBUG_SERVO: Servo pins initialized.");
        i++;
        if (i > 100) i = -100;
        writeServo(servo1, i, 1);
        writeServo(servo2, i, 2);
        writeServo(servo3, i, 3);
        writeServo(servo4, i, 4);
        delay(50);
    }
#endif

    setupI2C();
}

#if !defined(VIRTUAL_DEBUG) && !defined(DEBUG_I2C)
ISR(TIMER2_COMPA_vect)
{
    sbus.process();
}
#endif

void loop() {
    bool manualOverride = isManualOverride();

    int channel1 = manualOverride? getChannel(1) : desiredValueServo1;
    int channel2 = manualOverride? getChannel(2) : desiredValueServo2;
    int channel3 = manualOverride? getChannel(3) : desiredValueServo3;
    int channel4 = manualOverride? getChannel(4) : desiredValueServo4;
    writeServo(servo1, channel1, 1);
    writeServo(servo2, channel2, 2);
    writeServo(servo3, channel3, 3);
    writeServo(servo4, channel4, 4);

    if (lastI2CMessageTime < (millis() - I2C_RESET_TIMEOUT_MILLIS)) {
        setupI2C();
    }
}
#endif

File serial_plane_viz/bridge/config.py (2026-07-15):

# Bridge defaults. Edit here to change without passing CLI flags every time;
# all values can still be overridden with the matching --flag.

DEFAULT_BAUD_RATE = 115200
DEFAULT_WS_HOST = "localhost"
DEFAULT_WS_PORT = 8765
DEFAULT_HTTP_HOST = "localhost"
DEFAULT_HTTP_PORT = 8000

# Seconds to wait before retrying after the serial connection drops
# (device unplugged, port error, etc.).
RECONNECT_DELAY_SECONDS = 2.0

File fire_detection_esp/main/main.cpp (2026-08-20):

#include "esp_heap_caps.h"
#include "esp_log.h"
#include "freertos/FreeRTOS.h"
#include "freertos/task.h"

#include "i2c_task.hpp"
#include "image_provider.hpp"
#include "inference.hpp"

namespace {
const char *TAG = "main";

// Runs forever: grab a frame, run the CNN, log the result. Lives in its
// own task (rather than app_main's default task) so it doesn't block, and
// so it can be given a large-ish stack and pinned to a core independently
// of i2c_task (see i2c_task.cpp) -- the two run concurrently and don't
// share any state, so no locking is needed between them.
void inference_task_main(void *arg) {
    (void)arg;

    int width, height;
    fire_inference_get_input_size(&width, &height);
    const size_t image_len = (size_t)(width * height * 3);
    uint8_t *image_buf = static_cast<uint8_t *>(heap_caps_malloc(image_len, MALLOC_CAP_8BIT));
    if (!image_buf) {
        ESP_LOGE(TAG, "Failed to allocate %u byte image buffer", (unsigned)image_len);
        vTaskDelete(nullptr);
        return;
    }

    while (true) {
        if (image_provider_get_frame(image_buf, image_len, width, height) != ESP_OK) {
            ESP_LOGW(TAG, "image_provider_get_frame failed");
            vTaskDelay(pdMS_TO_TICKS(2000));
            continue;
        }

        fire_inference_result_t result;
        if (fire_inference_run(image_buf, image_len, &result) == ESP_OK) {
            ESP_LOGI(TAG, "Prediction: %s (score %.2f)", result.label, result.confidence);
        } else {
            ESP_LOGW(TAG, "fire_inference_run failed");
        }

        vTaskDelay(pdMS_TO_TICKS(2000));
    }
}
}  // namespace

extern "C" void app_main() {
    ESP_LOGI(TAG, "fire_detection_esp starting");

    esp_err_t err = fire_inference_init();
    if (err != ESP_OK) {
        ESP_LOGE(TAG, "fire_inference_init failed (%s) -- no model embedded yet? "
                       "See fire_detection_training/README.md.", esp_err_to_name(err));
        return;
    }

    err = i2c_task_start();
    if (err != ESP_OK) {
        ESP_LOGE(TAG, "i2c_task_start failed: %s", esp_err_to_name(err));
        // Not fatal for the inference path: keep going without I2C.
    }

    // Pinned to core 1, away from i2c_task (core 0) and the WiFi/BT stack
    // (also core 0 by default), since inference is the most CPU-heavy work
    // in this app. Stack is large because TFLM's interpreter and this
    // app's local buffers add up; 8192 is a safe starting point -- if it
    // crashes with a stack-overflow watchdog, bump it further.
    xTaskCreatePinnedToCore(inference_task_main, "inference_task", 8192, nullptr,
                             /*priority=*/5, nullptr, /*core=*/1);
}

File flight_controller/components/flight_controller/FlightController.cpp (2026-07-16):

//
// Created by Tom Arlt on 08.05.26.
//

#include "FlightController.hpp"

#include "Barometer.hpp"
#include "FlightStorage.hpp"
#include "GPS_Reader.hpp"
#include "Gyroscope.hpp"
#include "i2c_manager.hpp"
#include "mpu6050.h"
#include "Flight_Communication.hpp"
#include "LoRa_Communication.hpp"
#include "freertos/FreeRTOS.h"
#include "freertos/task.h"
#include <variant>

#include "geo_helper.hpp"
#include "route_planner.hpp"
#include "MotorComMaster.hpp"
#include "Magnetometer.hpp"
#include "OledDisplay.hpp"

static FlightControllerClass* flight_controller = nullptr;

FlightControllerClass& FlightController = FlightControllerClass::getInstance();

const char* FlightControllerClass::TAG_FLIGHT_CONTROLLER = "FlightController";

FlightControllerClass* FlightControllerClass::getInstancePtr() {
    if (flight_controller == nullptr) {
        flight_controller = new FlightControllerClass();
    }
    return flight_controller;
}

FlightControllerClass& FlightControllerClass::getInstance() {
    return *getInstancePtr();
}

FlightControllerClass::FlightControllerClass() = default;

void FlightControllerClass::init() {
    I2CManager::getBus(); // initialize I2C bus

    FlightStorage.init();

    LoRa_Communication.begin();

    Gyroscope.begin();
    Barometer.begin();
    Magnetometer.begin();
    GPS_Reader.begin();
    MotorComMaster.init();
    OledDisplay.begin();

    Flight_Communication::begin();

    xTaskCreate(flightTaskEntry, "FlightControllerFlightTask", 4096, this, tskIDLE_PRIORITY + 1, nullptr);
    xTaskCreate(sendUpdateTaskEntry, "FlightControllerSendUpdateTask", 4096, this, 10, nullptr);

    LoRa_Communication.registerReceivePacketCallback([this](const LoRaPacket packet) {
        communicationCallback(packet);
    });

    FlightStorage.registerDataChangeCallback([]() {
        ESP_LOGI(TAG_FLIGHT_CONTROLLER, "Planned route changed, sending update with size %d",
                 FlightStorage.getPlannedRoute().size());
        Flight_Communication::sendPlannedRoute();
        ESP_LOGI(TAG_FLIGHT_CONTROLLER, "Planned route sent");
    }, FlightStorageClass::DataUpdateType::ROUTE);

    vTaskDelay(pdMS_TO_TICKS(200));
}

void FlightControllerClass::flightTaskEntry(void* param) {
    auto* instance = static_cast<FlightControllerClass*>(param);
    instance->flightTask();
}

[[noreturn]] void FlightControllerClass::flightTask() {
    while (true) {
        if (plannedAreaChanged) {
            recalculateRoute();
        }

        auto currentTime = GPS_Reader.getGPSLatestTime();
        //auto planeAngle = Gyroscope.getAngle();
        auto position = FlightStorage.updatePlanePosition(GPS_Reader.getCurrentPosition(), currentTime);
        auto pressure = FlightStorage.updatePlanePressure(Barometer.getPressure(), currentTime);
        vTaskDelay(1);
        auto groundPressure = FlightStorage.getBasePressure();
        auto currentAltitude = altitudeAverage.push(BarometerClass::calculateAltitude(groundPressure, pressure));
        auto planeAngle = Gyroscope.getGroundAngle();
        planeAngle.roll = rollAverage.push(planeAngle.roll);
        planeAngle.pitch = pitchAverage.push(planeAngle.pitch);
        vTaskDelay(1);
        auto compassHeading = headingAverage.push(Magnetometer.getHeading());
        vTaskDelay(1);

        //ESP_LOGI("GNDANG", "roll: %f, pitch: %f, yaw deg: %f", planeAngle.roll, planeAngle.pitch, planeAngle.yaw);
        //ESP_LOGI("MAGN", "x: %.1f mG, y: %.1f mG, z: %.1f mG, heading: %.1f deg, ready: %d, locked: %d", magnetHeading.x, magnetHeading.y, magnetHeading.z, compassHeading, Magnetometer.isAvailable(), Magnetometer.isLocked());

        FlightStorage.updatePlaneGPSConnectionState(GPS_Reader.hasValidPosition()
                                                        ? ConnectionState::CONNECTED
                                                        : ConnectionState::CONNECTING);
        FlightStorage.updatePlaneBarometerConnectionState(Barometer.available()
                                                              ? ConnectionState::CONNECTED
                                                              : ConnectionState::CONNECTING);
        FlightStorage.updatePlaneMotorControlConnectionState(
            MotorComMaster.isSlaveConnected() ? ConnectionState::CONNECTED : ConnectionState::CONNECTING);
        FlightStorage.updatePlaneMagnetometerConnectionState(
            Magnetometer.isAvailable() ? ConnectionState::CONNECTED : ConnectionState::CONNECTING);
        FlightStorage.updatePlaneAccelerometerConnectionState(
            Gyroscope.initialized() ? ConnectionState::CONNECTED : ConnectionState::CONNECTING);
        FlightStorage.updatePlaneManualOverride(MotorComMaster.isManualOverride());
        FlightStorage.updatePlaneMotorControlConnectionState(
            MotorComMaster.isSlaveConnected() ? ConnectionState::CONNECTED : ConnectionState::CONNECTING);

        // advance waypoint index if close enough, then steer
        checkAndAdvanceWaypoint(position);

            steerToWaypoint(getNextWaypoint(), currentAltitude, planeAngle, compassHeading);
        vTaskDelay(pdMS_TO_TICKS(50));
    }
}

void FlightControllerClass::sendUpdateTaskEntry(void* param) {
    auto* instance = static_cast<FlightControllerClass*>(param);
    instance->sendUpdateTask();
}

[[noreturn]] void FlightControllerClass::sendUpdateTask() {
    while (true) {
        ESP_LOGI(TAG_FLIGHT_CONTROLLER, "Sending updates: position, sensor, component status");
        Flight_Communication::sendPosition();
        Flight_Communication::sendSensorUpdate();
        Flight_Communication::sendComponentStatus();
        vTaskDelay(pdMS_TO_TICKS(CONFIG_SEND_UPDATE_INTERVAL_MS));
    }
}
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

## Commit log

2026-05-06 switch flight controller from platformio to esp idf project
2026-05-07 switch base station to esp idf, fix compile and cleanup
    [main.cpp]
2026-05-09 get web interface and wifi working for base station
    [partitions.csv]
2026-05-22 get remote control switch/proxy working, prepare flight communication from esp to arduino
2026-06-02 fix bugs and refactor
    [Barometer.cpp, Gyroscope.cpp]
2026-06-04 fix lora communication bugs
    [Barometer.cpp, BaseController.cpp, FlightController.cpp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]
2026-06-22 cleanup bugfixes, motor communication/servo fixes, integration fixes
    [FlightController.cpp, FlightController.hpp, Gyroscope.cpp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]
2026-06-24 get magnetometer working
2026-06-28 bugfixes, adding magnetometer, and fix component statuses in webui
    [Barometer.cpp, BaseController.cpp, FlightController.cpp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]
2026-07-09 get magnetometer and i2c working again
2026-07-10 fix bugs in magnetometer, add heading to frontend
    [BaseController.cpp, FlightController.cpp, FlightController.hpp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]
2026-07-15 create case and mounting plate
    [base_station_case.scad, base_station_case_base.3mf, base_station_config.scad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]
2026-07-15 add 3d model for test plate
    [plane_mount_config.scad, plane_mount_plate.3mf, plane_mount_plate.scad]
2026-07-15 fix order of flight control commands sent to motor controller
    [MotorComMaster_esp.cpp]
2026-07-28 add motor controller debugging
2026-07-28 fix servo gain
2026-08-17 punkte masterarbeit aufschreiben und readme abgabe fixen/bearbeiten
2026-08-18 add schematics
    [schematics_base.fzz, schematics_plane.fzz]
2026-08-18 adding schematics to readmes
2026-08-18 final schematics update
    [schematics_base.fzz, schematics_plane.fzz]
2026-08-18 fix schematics and add info about sbus inverter
    [schematics_plane.fzz]
2026-08-18 fix remaining schematics and update linked file paths
    [schematics_base.fzz, schematics_plane.fzz]
2026-08-20 first attempt at CNN fire detection
    [partitions.csv]
